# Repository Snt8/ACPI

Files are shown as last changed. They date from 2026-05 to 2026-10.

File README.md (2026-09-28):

# 🚦 ACPI: Asistente de Cruce Peatonal para Invidentes v3.0 👨‍🦯➡️

## Descripción General
**ACPI** es un sistema **IoT de asistencia a la movilidad** diseñado para brindar **autonomía y seguridad** a personas con discapacidad visual al cruzar calles en intersecciones semaforizadas.

El sistema combina **hardware en el borde (Edge Computing)** con sensores magnéticos e inerciales locales en un brazalete (wearable) y en un semáforo (infraestructura). Utiliza comunicación local ultrarrápida (ESP-NOW) entre nodos y telemetría por Bluetooth Low Energy (BLE) hacia una aplicación móvil integrada con **Grafana Cloud** para monitorear la seguridad de la sesión.

---

## Contenido
El repositorio principal se divide en los siguientes componentes fundamentales:
- `/firmware/brazalete/` -> Código fuente (PlatformIO/C++) para el wearable (ESP32-C3 Super Mini).
- `/firmware/semaforo/` -> Código fuente (PlatformIO/C++) para la baliza de infraestructura (ESP32 DevKit V1).
- `/ACPIGPS/` -> Aplicación móvil Android nativa en Kotlin (Jetpack Compose).
- `/docs/` -> Documentación adicional y guías de configuración de la nube.
- `Justfile` -> Orquestador de tareas para compilación y *linting* automatizado.

---

## Explicación
### Arquitectura y Flujo de Procesamiento

El flujo de información se ejecuta de la siguiente forma:

```text
[Semáforo ESP32]  ──ESP-NOW──►  [Brazalete ESP32-C3]  ──BLE──►  [App Android]  ──HTTPS──►  [Grafana Cloud]
 QMC6308                         QMC6308 + MPU6050              GPS + Pasos
 2 LEDs simulan                  Brújula + Decisión              Registro sesiones
 semáforo                        Feedback háptico                Telemetría
 (sin WiFi/Internet)             FSM de 2Hz
```

1. **Semáforo (Infraestructura)**: Un ESP32 DevKit V1 equipado con un magnetómetro lee su orientación magnética estática y simula un ciclo de semáforo verde/rojo. Transmite su orientación (heading) y estado por ESP-NOW a 2Hz (cada 500ms).
2. **Brazalete (Wearable)**: Actúa como el centro de cómputo en el borde. Lee su orientación tilt-compensada (acelerómetro + magnetómetro), y calcula la diferencia angular frente a la infraestructura. Si detecta que el usuario está correctamente enfrentado (`|Δθ - 180°| < 30°`), provee feedback háptico diferenciado mediante dos micromotores de vibración.
3. **App Android**: Recibe mediante BLE los paquetes de telemetría del brazalete, controla geocercas y envía métricas asíncronas.
4. **Grafana Cloud**: Ingesta los datos del usuario asíncronamente para generar mapas y analíticas en tiempo real.

---

## Dependencias
- **Hardware**: 
  - ESP32-C3 Super Mini, ESP32 DevKit V1.
  - MPU6050 (Acelerómetro/Giroscopio) y QMC6308 (Magnetómetro I2C).
  - Micro-motores de vibración 3V tipo moneda.
- **Software**: 
  - [PlatformIO](https://platformio.org/) para el desarrollo y flasheo C++ del firmware.
  - [Just](https://github.com/casey/just) como *command runner* (opcional pero recomendado).
  - Android Studio para compilar la App.

---

## Ejemplo de Uso

Para compilar e inyectar el código en los microcontroladores usando PlatformIO, primero asegúrate de tener instaladas las dependencias.

Con **Just** (Recomendado):
```bash
# Compilar todo el ecosistema firmware
just compile-all

# Flashear el semáforo y el brazalete (asegúrate de conectarlos vía USB)
just flash-semaforo
just flash-brazalete
```

Sin **Just** (Usando PlatformIO CLI directo):
```bash
pio run -d firmware/brazalete --target upload
pio run -d firmware/semaforo --target upload
```

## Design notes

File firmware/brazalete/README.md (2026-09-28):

# Firmware Brazalete (Wearable ACPI)

## Descripción General
Este es el código fuente principal del **Nodo Maestro (Brazalete)** del proyecto ACPI. Diseñado para correr sobre un microcontrolador **ESP32-C3 Super Mini**, actúa como un procesador _Edge Computing_ portátil y de ultrabajo consumo. Es responsable de recopilar lecturas inerciales y magnéticas, evaluar la orientación peatonal contra las señales del semáforo, emitir respuestas físicas (hápticas) al usuario y transmitir los resultados de telemetría al smartphone.

---

## Contenido
- `platformio.ini` -> Archivo de configuración de construcción de PlatformIO (Framework `espressif32@6.9.0`).
- `include/` -> Constantes globales y configuraciones macro (`config.h`, `constantes.h`).
- `src/main.cpp` -> Punto de entrada del programa.
- `lib/` -> Submódulos independientes (brújula, sensores, control, motores, comunicación, utilidades).

---

## Explicación
El firmware está construido bajo un enfoque altamente modular y orientado a eventos discretos, implementando una **Máquina de Estados Finita (FSM)**.

En su estado nominal de `SENSING_CROSSING`, el brazalete ejecuta un ciclo de muestreo estricto a **2 Hz (cada 500ms)** en el que realiza las siguientes operaciones en menos de un milisegundo de CPU, maximizando el tiempo inactivo:
1. Lee los componentes vectoriales $g_x, g_y, g_z$ del MPU6050.
2. Extrae las lecturas crudas del QMC5883L y les aplica compensación ambiental _Hard-Iron_ mediante un _Leaky Integrator_.
3. Compensa tridimensionalmente el compás magnético (_Tilt Compensation_) para obtener el Heading puro.
4. Aplica una barrera protectora de movimiento brusco (_Safety Check_): Ignora lecturas si el Heading giró $>40^{\circ}$ en medio segundo.
5. Evalúa matemáticamente la diferencia frente al rumbo transmitido por el Semáforo.
6. Enciende los micro-motores usando rutinas no-bloqueantes.

---

## Dependencias
- **NimBLE-Arduino**: Biblioteca optimizada para gestionar Bluetooth Low Energy ocupando mucho menos memoria RAM y Flash que la biblioteca oficial, ideal para el restringido ESP32-C3.
- **Wire (I2C)**: Framework nativo de Arduino para la comunicación con los sensores.
- **ESP-NOW**: Protocolo ultrarrápido sin conexión de Espressif.

---

## Ejemplo de Uso

Dado que el entorno depende de PlatformIO, la construcción del brazalete se maneja desde la raíz del proyecto.

```bash
# Navegar a la raíz del proyecto ACPI
cd ../../

# Ejecutar el Linter de calidad de código
pio check -d firmware/brazalete

# Compilar el código
pio run -d firmware/brazalete

# Compilar y cargar en la ESP32-C3 por puerto USB
pio run -d firmware/brazalete --target upload
```

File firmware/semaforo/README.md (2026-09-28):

# Firmware Semáforo (Infraestructura ACPI)

## Descripción General
Este es el código fuente principal del **Nodo Esclavo (Semáforo)** del proyecto ACPI. Está diseñado para ejecutarse en una placa de desarrollo **ESP32 DevKit V1** (o compatible) anclada de manera estática y fija en la intersección peatonal.

Su misión principal es leer el campo magnético direccional permanente hacia donde cruza la calle (su propia orientación), simular visualmente mediante LEDs el estado de permiso de vía (Verde/Rojo para vehículos), y disparar de forma constante la información (telemetría) a los brazaletes cercanos usando difusión de radio (Broadcast).

---

## Contenido
- `platformio.ini` -> Archivo de configuración de construcción de PlatformIO (Framework `espressif32@6.9.0`).
- `include/` -> Constantes globales (Ej: Tiempos de duración de la luz verde o roja) y configuración (`config.h`, `const.h`).
- `src/main.cpp` -> Punto de entrada y Máquina de Estados Finita (FSM) basada en tiempo del semáforo.
- `lib/` -> Submódulos de hardware y red (`brujula`, `comunicacion`, `protocolo`).

---

## Explicación
A diferencia del brazalete que es impulsado por eventos, el semáforo está impulsado por reloj (Temporizadores):

1. Mantiene un bucle continuo de `millis()` verificando si la duración preconfigurada del estado actual del semáforo (ej: 30 segundos) ha expirado. Si expira, alterna el relé/LED y cambia internamente su estado booleano de `permitidoCruce`.
2. A una tasa paralela e independiente, lee periódicamente (ej: 2 Hz) el magnetómetro I2C para obtener su propia dirección en grados frente al polo magnético terrestre.
3. Empaqueta el tiempo que le resta a la luz actual, los grados y la validación en una estructura C empaquetada.
4. Invoca la radio ESP-NOW, propagando la carga en modo BROADCAST (Mac: `FF:FF:FF:FF:FF:FF`). Todo brazalete en rango capturará esta ráfaga de forma pasiva.

---

## Dependencias
- Librería base **Arduino.h**.
- Bus I2C de Espressif (`<Wire.h>`).

---

## Ejemplo de Uso

Para compilar y cargar localmente:

```bash
# Cambiar al directorio raíz
cd ../../

# Ejecutar linters de calidad
pio check -d firmware/semaforo

# Compilar para la placa DevKit
pio run -d firmware/semaforo

# Flashear al hardware conectado por USB
pio run -d firmware/semaforo --target upload
```

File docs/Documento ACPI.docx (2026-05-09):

ASISTENTE DE CRUCE PEATONAL PARA INVIDENTES

Andrea Carolina Cárdenas Rojas

Dilan Santiago Osorio Bernate

Nicolás Ernesto Rodríguez Avella

Asesora

Johanna Carolina Sánchez Ramírez

Escuela Tecnológica Instituto Técnico Central.

Especialidad de sistemas

Grupo III

2025

Tabla de Contenido

# Identificación del problema

Moverse por la ciudad puede parecer algo sencillo para la mayoría de las personas, pero para quienes tienen discapacidad visual, puede convertirse en una experiencia bastante difícil y hasta peligrosa. Desde salir de casa, caminar por una acera, esquivar obstáculos o cruzar una calle, cada paso puede representar un riesgo si no se cuenta con las herramientas necesarias. Uno de los momentos más delicados es al cruzar una calle con semáforo, ya que estos dispositivos están hechos para personas que pueden ver, sin tener en cuenta a quienes no pueden hacerlo. Esto significa que, aunque el semáforo esté en rojo para los vehículos, la persona con discapacidad visual no siempre tiene forma de saberlo con claridad y seguridad.

Aunque hay bastones y perros guías que les brindan orientación en muchos aspectos del camino, muchas veces no hay herramientas tecnológicas accesibles que realmente les ayuden a cruzar con confianza. En la mayoría de los casos, estas personas deben adivinar si pueden cruzar o esperar a que alguien las ayude, lo que no solo pone en riesgo su seguridad, sino que también afecta su autonomía, su tranquilidad y su capacidad de movilizarse libremente.

Es urgente responder a esta necesidad con una solución tecnológica accesible y práctica, que les proporcione mayor seguridad en el cruce de calles. Mejorar su experiencia de movilidad urbana no solo impacta en su calidad de vida, sino que también representa un paso hacia una ciudad más inclusiva, que considere a todos sus habitantes en igualdad de condiciones.

Dado esto, nuestro objetivo general es diseñar un sistema portátil con señal vibratoria que indique cuándo es seguro cruzar una calle con semáforo para brindar mayor seguridad y autonomía a personas con discapacidad visual en espacios urbanos.

# Investigación y Análisis

El proyecto ACPI busca crear un sistema asistido que ayude a personas con discapacidad visual a cruzar calles de manera más segura. Para lograrlo, se usan tecnologías como microcontroladores, comunicación inalámbrica, vibración háptica y posicionamiento GPS. Conocer los fundamentos técnicos y teóricos de estas herramientas es clave para asegurar que el sistema funcione bien, sea útil y tenga un impacto positivo en la sociedad.

Componentes clave:

- ESP32: Es un microcontrolador económico y potente con Wi-Fi y Bluetooth, ideal para proyectos inalámbricos. Gracias a su bajo consumo, es apto para dispositivos portátiles (Espressif Systems, 2020).
- ESP-NOW: Protocolo creado por Espressif que permite la comunicación directa entre dispositivos sin internet, útil en sistemas que requieren respuesta rápida y autónoma.
- Motor vibrador: Dispositivo pequeño que genera vibración como señal de alerta. Se usa comúnmente en celulares y relojes.
- GPS: Sistema que usa satélites para obtener ubicación en tiempo real. En este proyecto se emplea a través del celular del usuario (NASA, 2018).
- TP4056: Módulo que permite recargar baterías de litio de forma segura, evitando sobrecargas.
- XL6009: Elevador de voltaje que convierte, por ejemplo, 3.7V en 5V para alimentar componentes electrónicos.
- Arduino y C++: Arduino es una plataforma de desarrollo que se programa en C++, permitiendo controlar sensores y actuadores fácilmente, ideal para prototipos.

En varios países se han propuesto soluciones similares. En España, la aplicación SeeLight notifica a personas ciegas cuando el semáforo está en verde (Fundación Montemadrid, 2015). También, en Granada, LabIN desarrolló semáforos accesibles con botones y sonidos. Sin embargo, muchos de estos sistemas dependen de la verificación y uso respecto al celular del usuario o de infraestructura urbana costosa. ACPI busca ser más sencillo, portátil y económico, funcionando incluso en zonas sin internet ni semáforos sonoros, como entornos escolares o rurales.

Este proyecto se basa en la tecnología asistida, definida por la OMS (2004) como cualquier herramienta que mejora la funcionalidad de personas con discapacidad. También se relaciona con el modelo social de la discapacidad, que señala que las limitaciones no están en la persona, sino en el entorno. Bajo esta mirada, ACPI busca eliminar barreras a través de tecnología accesible y funcional.

Comprender estos conceptos técnicos y teóricos permite diseñar una solución que responda a las necesidades reales del usuario. Saber cómo funciona el ESP32, el protocolo ESP-NOW, los motores vibradores y los módulos de energía ayuda a tomar buenas decisiones al construir el prototipo. Además, los antecedentes muestran que esta necesidad existe y que es posible hacerla realidad con herramientas simples, económicas y bien diseñadas.

## Propuesta de solución

Nombre del proyecto: ACPI – Asistente de Cruce para Personas Invidentes

Descripción de la solución: ACPI es un sistema portátil diseñado para mejorar la seguridad de personas con discapacidad visual al momento de cruzar calles con semáforo. El dispositivo consiste en una pulsera que recibe de manera inalámbrica, mediante tecnología ESP32 y protocolo ESP-NOW, la información procesada desde el entorno del semáforo. Al determinar que el cruce es seguro, la pulsera emite una señal vibratoria clara y perceptible para el usuario.

La solución combina el uso del microcontrolador ESP32 con componentes de bajo consumo energético, alimentados por una batería recargable y programados en C++ a través de la plataforma Arduino. Para futuras versiones, la aplicación móvil se integrará con el GPS y la brújula del celular, lo que permitirá funciones adicionales de ubicación y orientación sin necesidad de añadir más hardware al dispositivo.

Objetivos específicos:

1. Analizar las dificultades que enfrentan las personas con discapacidad visual al cruzar calles con semáforo para asegurar que el sistema responda a sus necesidades reales en contextos urbanos transitados.
2. Construir un módulo que detecte la luz roja del semáforo mediante un sensor de luz calibrado para enviar información clara al usuario desde un punto fijo cercano al semáforo.
3. Diseñar una pulsera portátil basada en ESP32 que reciba la señal del semáforo mediante comunicación inalámbrica y active un motor vibrador para alertar al usuario sobre el momento seguro de cruce.
4. Vincular la aplicación móvil con el GPS y la brújula del celular, de manera que el sistema quede preparado para futuras funciones de orientación y seguimiento de rutas en espacios urbanos.
5. Evaluar la comodidad, duración de la batería y facilidad de uso del sistema para asegurar que sea práctico en el día a día en manos de personas con discapacidad visual

Criterios de funcionamiento:

- El dispositivo debe recibir la señal del nodo semafórico en tiempo real.
- Debe vibrar únicamente cuando el cruce sea seguro.
- El sistema debe ser ligero, portátil y fácil de usar.
- La batería debe durar varios días y poder recargarse fácilmente.
- Debe operar sin fallos en la comunicación entre ambos dispositivos.
- Debe activarse y apagarse manualmente para ahorrar energía.

## Diseño del Prototipo

Lista de materiales:

- 2 módulos ESP32 (uno para el semáforo y otro para el usuario)
- 1 sensor de luz fotorresistencia LDR (para detectar el estado del semáforo)
- 1 motor vibrador (para la señal háptica)
- 1 módulo TP4056 (para carga segura de la batería)
- 1 batería de litio recargable de 3.7V
- 1 elevador de voltaje XL6009 (para alimentar los 5V de la pulsera)
- 1 interruptor deslizante con marca táctil física (muesca o relieve) para que el usuario pueda identificar por tacto las posiciones ON/OFF
- Cables Dupont
- Soldadura para circuito final
- Pulsera o carcasa impresa en 3D
- Computador con Arduino IDE y Android Studio instalado

Funcionamiento técnico:
Cuando el semáforo está en rojo para los vehículos (es decir, seguro para cruzar), el sensor de luz activa el ESP32 fijo, que envía una señal inalámbrica mediante ESP-NOW al dispositivo del usuario. Al recibir la señal, el ESP32 portátil activa el motor vibrador, indicando que es momento de cruzar. El sistema se apaga manualmente para conservar batería. La aplicación móvil complementará la experiencia usando el GPS y brújula del celular para ofrecer navegación y mejor orientación espacial.

Roles del equipo:

- Dilan: Programación del sistema en C++ (Arduino IDE), pruebas de comunicación ESP-NOW, diseño físico del prototipo, armado del circuito y cuidado del montaje portátil.
- Andrea: Diseño y programación de la aplicación móvil, integración del GPS y brújula del celular, desarrollo de README.md.
- Nicolás: Documentación escrita, organización general del cronograma y entregables, investigación técnica de componentes, redacción y soporte teórico.

## Construcción y Pruebas

Prototipo 1 (Micro: bit)

Proceso de construcción:

1. Diseño de la carcasa en software 3D con espacios para Micro: bit, motor vibrador y batería con su respectiva carcasa.
2. Impresión en PLA rígido de toda la estructura en dos piezas (ver foto).
3. Montaje de componentes dentro de la carcasa: Micro: bit y motor vibrador.
4. Conexionado de los cables de señal y alimentación con soldadura y cinta aislante.
5. Ajuste de la pulsera al brazo con correas elásticas.

Resultados:

- El Micro: bit y el motor vibrador funcionaron correctamente al enviar la señal.
- La carcasa protegió bien los componentes y la batería se mantuvo estable durante el uso.

Errores y limitaciones:

- La rigidez del PLA hacía la pulsera muy incómoda para la muñeca.
- Los cables quedaron muy expuestos y voluminosos, dificultando el uso diario.
- El diseño no era práctico ni estéticamente atractivo.

Fotos: (ver anexo)

Prototipo 2 (plástico flexible con ESP32)

Proceso de construcción:

Se plantea un rediseño completo de la carcasa, adaptándola al uso del microcontrolador ESP32 y a los demás componentes electrónicos. La estructura busca ser más compacta y modular, facilitando el montaje y el mantenimiento.

La carcasa sería en un plástico flexible para mejorar la comodidad al contacto con la piel y permitir un ajuste más ergonómico en la muñeca del usuario. El diseño se divide en dos módulos principales: uno destinado a alojar la electrónica (ESP32, batería y módulo de carga) y otro para la disposición de los cables, con el fin de optimizar el espacio y mejorar la organización interna. El montaje está previsto mediante encajes pequeños y una correa de silicona ajustable, lo que facilita tanto el uso cotidiano como el reemplazo de piezas en caso necesario.

Como referencia, se incluirá una fotografía del dispositivo sin carcasa, mostrando la disposición inicial de la pulsera con los componentes expuestos, lo que permite visualizar la organización interna antes del encapsulado final.

Fotos: (ver anexo)

# Evaluación del Prototipo

Resultados generales:
El prototipo ACPI logró cumplir su función principal de asistir al usuario en el cruce de calles, mediante la sincronización con semáforos y la transmisión de alertas vibratorias. En pruebas controladas, el sistema respondió adecuadamente y permitió validar la interacción entre la aplicación móvil y la pulsera.

Limitaciones encontradas:

- Autonomía de la batería limitada a menos de 8 horas.
- Incompatibilidad con algunos modelos de celulares Android/iOS.
- Carcasa poco ergonómica y de tamaño incómodo para muñecas pequeñas.
- Sensibilidad de la detección a cambios de luz ambiente (día/noche).
- Presupuesto reducido para mantenimiento o reemplazo de piezas.

Problemas técnicos:

- Pérdida de señal entre el celular/ESP32 y la pulsera en zonas con interferencia.
- Retraso en la sincronización con los semáforos cuando la vibración no es precisa.
- Riesgo de deterioro rápido en la correa y falta de resistencia al agua.

Análisis con Diagrama de Ishikawa: (ver diagrama en anexo)

# Conclusiones y Recomendaciones

Conclusiones técnicas:

- El prototipo ACPI es funcional y logra asistir al usuario en el cruce de calles mediante alertas vibratorias sincronizadas con los semáforos.
- La integración entre la aplicación móvil, el ESP32 y la pulsera demuestra la viabilidad del uso de tecnologías accesibles en contextos sociales.
- Se adquirió experiencia en la implementación de sistemas electrónicos, programación móvil y validación de usabilidad con usuarios reales.

Recomendaciones futuras:

- Optimizar la autonomía del sistema incorporando baterías de mayor capacidad.
- Mejorar la ergonomía de la pulsera, reduciendo su tamaño y empleando materiales más resistentes al agua y al desgaste.
- Probar el funcionamiento del sistema completo (sensor y pulsera) en un entorno para comprobar la efectividad de la comunicación y la señal vibratoria con usuarios simulando situaciones reales de cruce
- Realizar pruebas en entornos reales con usuarios finales para refinar la precisión de la sincronización y la usabilidad del dispositivo.

# Anexos

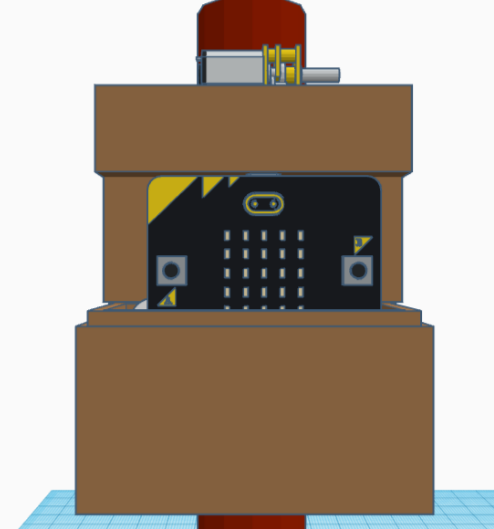
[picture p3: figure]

Prototipo 1 (Micro: bit)

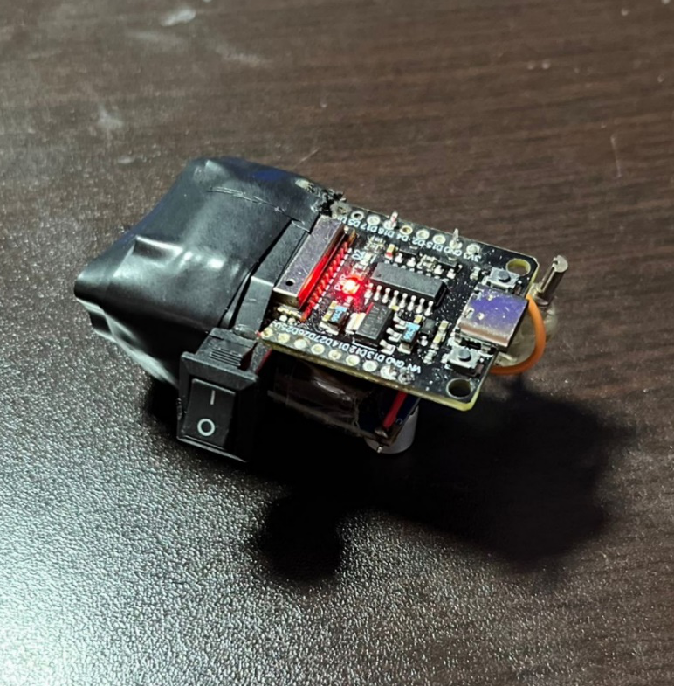
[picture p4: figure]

Prototipo 2 sin carcasa

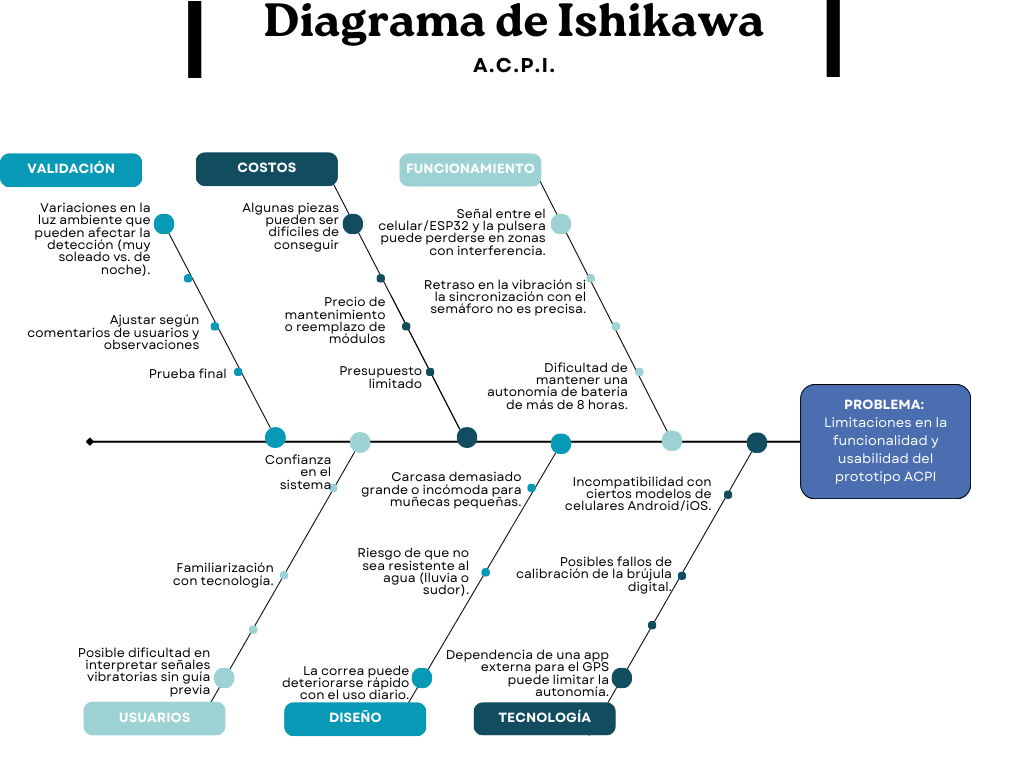
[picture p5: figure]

Análisis con Diagrama de Ishikawa

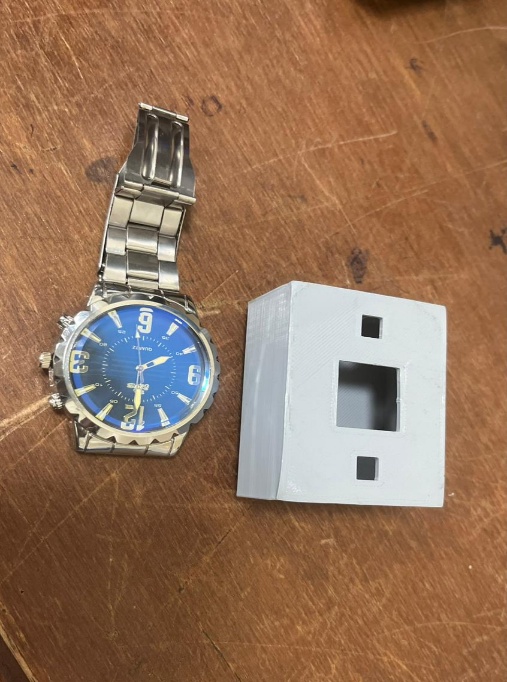
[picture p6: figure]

Imagen 1 Comparación de tamaños del reloj

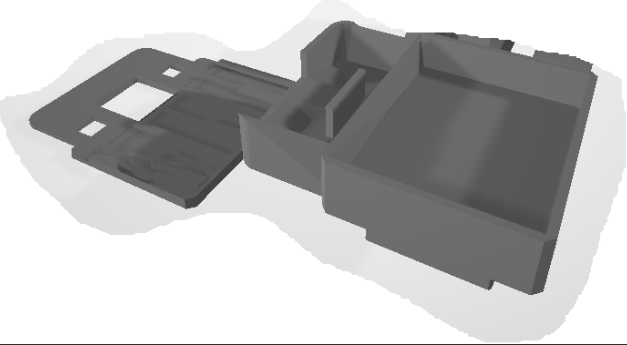
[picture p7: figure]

Imagen 2 Diseño previo de la pulsera

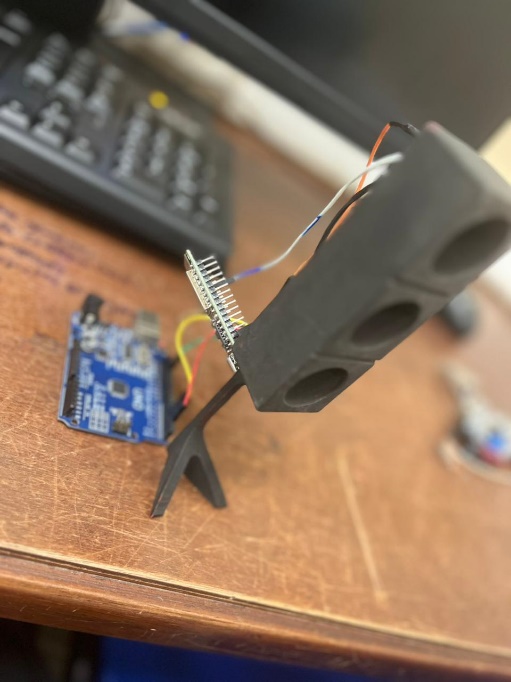
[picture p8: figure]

Imagen 3 Nuevo diseño con ESP-32

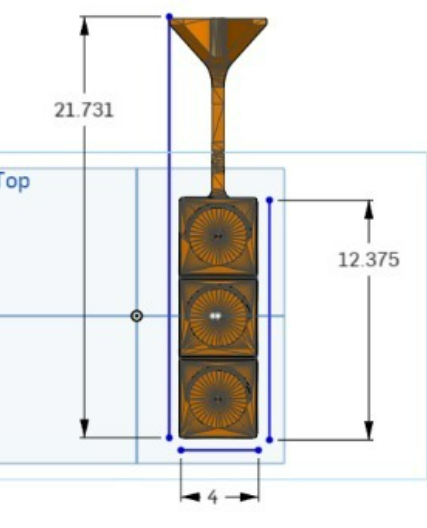
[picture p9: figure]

Imagen 4 Nuevo diseño con ESP-32

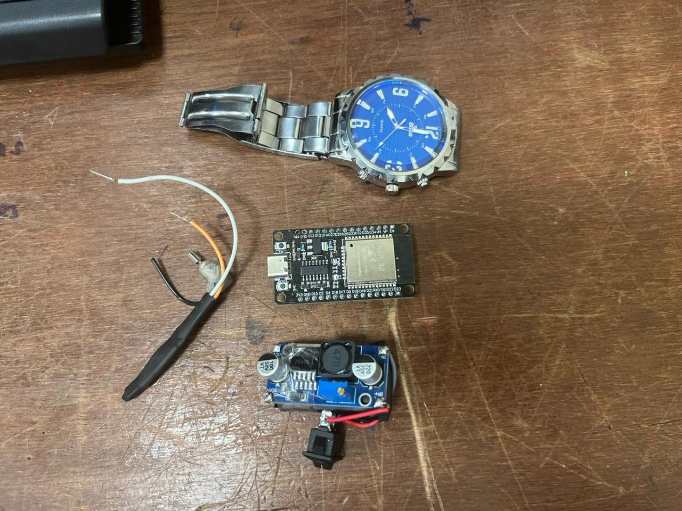
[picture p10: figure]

Imagen 5 Comparación tamaños

# Referencias

- CityTV. (2024, 14 de marzo). Bogotá tendría un déficit de semáforos sonoros para personas ciegas. El Tiempo. https://citytv.eltiempo.com/programas/citynoticias-del-mediodia/bogota-tendria-un-deficit-de-semaforos-sonoros-para-personas-ciegas_63112
- Congreso de Colombia. (2013). Ley 1618 de 2013: Por medio de la cual se establecen las disposiciones para garantizar el pleno ejercicio de los derechos de las personas con discapacidad. Diario Oficial No. 48.717. https://www.funcionpublica.gov.co/eva/gestornormativo/norma.php?i=52081
- LaBiN Granada. (s.f.). Semáforos para invidentes. Laboratorio de Innovación Pública de Granada. https://labingranada.org/idea/semaforos-para-invidentes/

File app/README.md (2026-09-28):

# ACPI Android Mobile Application (ACPIGPS)

## Descripcion General
La aplicación móvil **ACPIGPS** actúa como el puente de comunicaciones central del ecosistema ACPI. Su función principal es conectarse mediante **Bluetooth Low Energy (BLE)** al Brazalete Inteligente (ESP32-C3), procesar sus notificaciones de estado y orientación magnética en tiempo real, guiar al peatón de manera visual/auditiva y reportar las métricas agregadas de cada sesión de cruce de forma segura y resiliente hacia el backend de **Grafana Cloud** mediante payloads JSON simplificados.

## Contenido
La aplicación está organizada en torno a los siguientes archivos y submódulos principales en `app/src/main/java/com/example/acpigps/`:
- **[MainActivity.kt](file:///c:/Users/sntav/programacion/ACPI/ACPIGPS/app/src/main/java/com/example/acpigps/MainActivity.kt)**: Punto de entrada de la UI y gestión de navegación basada en Jetpack Compose.
- **[BLEManager.kt](file:///c:/Users/sntav/programacion/ACPI/ACPIGPS/app/src/main/java/com/example/acpigps/BLEManager.kt)**: Manejador GATT cliente que gestiona el escaneo, emparejamiento, suscripción a notificaciones y envío de comandos al brazalete.
- **[GrafanaReporter.kt](file:///c:/Users/sntav/programacion/ACPI/ACPIGPS/app/src/main/java/com/example/acpigps/GrafanaReporter.kt)**: Módulo encargado del formateo de telemetría y su envío mediante HTTP POST asíncrono con un buffer resiliente ante pérdidas de conectividad.
- **[MonitoringService.kt](file:///c:/Users/sntav/programacion/ACPI/ACPIGPS/app/src/main/java/com/example/acpigps/MonitoringService.kt)**: Servicio en primer plano (Foreground Service) que garantiza que las conexiones BLE y de red sigan activas incluso si la pantalla se apaga.
- **[WalkDirectionDetector.kt](file:///c:/Users/sntav/programacion/ACPI/ACPIGPS/app/src/main/java/com/example/acpigps/WalkDirectionDetector.kt)**: Detector lógico de pasos y patrones de desplazamiento.
- **[SessionLogger.kt](file:///c:/Users/sntav/programacion/ACPI/ACPIGPS/app/src/main/java/com/example/acpigps/SessionLogger.kt)**: Registro local en formato de texto dentro del almacenamiento del dispositivo.
- **[BrazaleteData.kt](file:///c:/Users/sntav/programacion/ACPI/ACPIGPS/app/src/main/java/com/example/acpigps/BrazaleteData.kt)**: Modelo de datos que mapea la telemetría recibida por BLE.

## Explicacion
### 1. Comunicación BLE (GATT Cliente)
La app implementa el perfil GATT cliente interactuando con los UUIDs definidos en el firmware del brazalete:
- **Servicio Principal**: `12345678-1234-1234-1234-123456789abc`
- **Característica TX (Notificación)**: `87654321-4321-4321-4321-cba987654321` (Recibe el JSON con rumbo, alineación y estado de cruce cada 500 ms).
- **Característica RX (Escritura)**: `11111111-2222-3333-4444-555555555555` (Envía comandos de control o cuadrantes de rumbo al ESP32).

### 2. Resiliencia de Telemetría (GrafanaReporter)
Para cumplir con los estándares de bajo consumo y resiliencia, `GrafanaReporter` implementa un buffer circular en memoria (`ConcurrentLinkedQueue`) de hasta 100 elementos. 
- Al completarse una sesión, el JSON se añade a la cola y se intenta realizar el POST asíncrono usando `OkHttpClient`.
- Si la conexión de red falla, el payload se mantiene en cola y se reintenta en el próximo envío.
- Si las credenciales (`grafana_url` y `grafana_token`) no se encuentran configuradas en `SharedPreferences` (bajo el archivo `app_prefs`), el reporte falla silenciosamente para no bloquear la ejecución principal.

## Dependencias
Las principales dependencias declaradas en el archivo de construcción Gradle de la app son:
- **OkHttp (v4.x+)**: Para las peticiones de red asíncronas y seguras hacia Grafana Cloud.
- **Android Bluetooth Suite**: APIs nativas de Android SDK para operaciones de escaneo y conectividad GATT.
- **Jetpack Compose**: Framework UI moderno para la renderización de pantallas.
- **Lifecycle & LiveData**: Gestión del estado reactivo entre la lógica de negocio y la interfaz de usuario.

## Ejemplo de Uso
A continuación se ilustra cómo el servicio interactúa con el reportero de telemetría al finalizar un cruce peatonal:

```kotlin
// Instanciación del reportero
val reporter = GrafanaReporter(context)

// Creación de las métricas de la sesión
val metrics = JSONObject().apply {
    put("duration_sec", 30)
    put("waiting_sec", 12)
    put("steps", 45)
    put("panics", 0)
    put("lat", 19.4326)
    put("lon", -99.1332)
}

// Envío asíncrono y resiliente
reporter.sendSessionTelemetry(
    deviceId = "ACPI_Brazalete",
    sessionId = UUID.randomUUID().toString(),
    status = 1, // 1 = Cruce exitoso y alineado
    metrics = metrics
)
```

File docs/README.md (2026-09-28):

# Especificaciones de Protocolos, Telemetría e Integración (ACPI)

## Descripcion General
Este directorio contiene la documentación técnica y las especificaciones de arquitectura para la comunicación de red, los protocolos inalámbricos y la integración con el sistema de telemetría y visualización de datos en la nube. Define cómo interactúan el Brazalete Inteligente, el Semáforo, la Aplicación Móvil y el panel de control de Grafana Cloud.

## Contenido
El directorio incluye los siguientes documentos técnicos especializados:
- **[ble-protocol.md](file:///c:/Users/sntav/programacion/ACPI/docs/ble-protocol.md)**: Especificación técnica detallada del protocolo de comunicación Bluetooth Low Energy (BLE) entre el Brazalete (servidor GATT) y el dispositivo Android (cliente GATT).
- **[grafana-setup.md](file:///c:/Users/sntav/programacion/ACPI/docs/grafana-setup.md)**: Guía paso a paso para la configuración del ingestor de datos en Grafana Cloud, mapeo de variables JSON de telemetría y diseño de paneles recomendados.

## Explicacion
### 1. Topología Inalámbrica Dual
El sistema ACPI utiliza una separación estricta de protocolos según el dispositivo:
- **Brazalete (ESP32-C3)**: Utiliza **BLE únicamente** para comunicarse con el celular del peatón. Tiene prohibido levantar la pila Wi-Fi para optimizar la batería.
- **Semáforo (ESP32 DevKit V1)**: Transmite periódicamente su orientación y estado magnético al brazalete a través de **ESP-NOW** en modo broadcast (2Hz).
- **Celular (App Android)**: Recibe los datos vía BLE y, cuando finaliza una sesión de cruce, utiliza la red móvil (Wi-Fi o Datos) para enviar las métricas agregadas por HTTP Push (POST) a Grafana Cloud.

### 2. Formato del Payload de Telemetría
Para reducir la carga en la red móvil del usuario, el JSON de sesión se mantiene en una sola jerarquía (plano), facilitando la ingesta directa en bases de datos de series temporales (como InfluxDB o Prometheus):
- **`device_id`**: Identificador de hardware.
- **`session_id`**: UUID generado por la aplicación para rastrear el cruce actual.
- **`status`**: Estado final codificado numéricamente (`0` = Espera, `1` = Cruce seguro/alineado, `2` = Desalineado, `3` = Alerta de pánico).
- **Métricas físicas**: Pasos (`steps`), duración (`duration_sec`), y geolocalización (`lat` y `lon`).

## Dependencias
Para implementar e interactuar con estos protocolos e integraciones, se requiere:
- **Pila BLE v4.2 o superior**: Compatible con GATT en ESP32-C3 y el sistema operativo Android.
- **Servicio Grafana Cloud (Free Tier)**: O bien un gateway/broker local (Mosquitto/MQTT) capaz de procesar peticiones HTTP JSON.

## Ejemplo de Uso
Ejemplo de cómo reportar manualmente un evento de cruce de prueba al endpoint HTTP de Grafana Cloud (o gateway compatible) utilizando `curl`:

```bash
curl -X POST "https://influx-prod-13-prod-us-east-0.grafana.net/api/v1/push" \
  -H "Authorization: Bearer glc_eyJ..." \
  -H "Content-Type: application/json" \
  -d '{
    "device_id": "ACPI_Brazalete_Test",
    "session_id": "99999999-9999-9999-9999-999999999999",
    "status": 1,
    "timestamp": 1780704000000,
    "duration_sec": 28,
    "waiting_sec": 8,
    "steps": 32,
    "panics": 0,
    "lat": 19.4326,
    "lon": -99.1332
  }'
```

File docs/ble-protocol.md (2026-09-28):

# Protocolo de Comunicación BLE (Brazalete ◄► App)

Este documento detalla el protocolo de comunicación inalámbrica vía **Bluetooth Low Energy (BLE)** utilizado entre el **Brazalete Inteligente** (Servidor GATT) y la **Aplicación Android** (Cliente GATT).

---

## 1. Identificación y Servicios GATT

El brazalete se anuncia con el nombre del dispositivo **`ACPI_Brazalete`**.

### UUIDs del Perfil GATT:
- **Servicio Principal**: `12345678-1234-1234-1234-123456789abc`
- **Característica de Transmisión (TX - Notificaciones)**: `87654321-4321-4321-4321-cba987654321`
  * *Permiso*: Notificación (Notify). El brazalete empuja datos aquí periódicamente.
- **Característica de Recepción (RX - Escritura)**: `11111111-2222-3333-4444-555555555555`
  * *Permiso*: Escritura sin respuesta (Write Without Response / Write). La app escribe comandos aquí.

---

## 2. Payload de Telemetría (Brazalete ──► App)

El brazalete transmite cada **500 ms** (cuando hay conexión y está en estado activo de cruce o pánico) un JSON compacto en texto plano UTF-8 a través de la característica **TX**:

```json
{"hd":135,"st":1,"ok":true,"tr":18,"bt":-1}
```

### Especificación de Campos:

| Clave | Tipo | Rango | Descripción |
|---|---|---|---|
| **`hd`** | Entero | `0` a `359` | **Heading**: Orientación magnética tilt-compensada actual del brazalete. |
| **`st`** | Entero | `0` a `3` | **Status**: Estado actual del cruce determinado por el brazalete:<br>• `0`: Espera (Semáforo en verde de autos, peatón debe esperar).<br>• `1`: Cruce Permitido (Semáforo en rojo de autos, peatón alineado).<br>• `2`: Orientación Incorrecta (El peatón no está mirando en la dirección del semáforo).<br>• `3`: Alerta de Pánico (Botón de pánico presionado por el usuario). |
| **`ok`** | Booleano | `true` / `false` | **Alineación**: `true` si el heading del brazalete coincide con el heading del semáforo dentro del umbral (±45°). |
| **`tr`** | Entero | `0` a `255` | **Tiempo Restante**: Segundos restantes en el estado actual del semáforo. |
| **`bt`** | Entero | `-1` o `0` a `100` | **Batería**: Nivel de batería en porcentaje. Si el hardware no posee divisor resistivo en ADC para medir batería, se reportará **`-1`** (no disponible). |

---

## 3. Comandos de Control (App ──► Brazalete)

La aplicación móvil puede enviar comandos a través de la característica **RX** para propósitos de prueba y depuración:

- **`TEST_ALERT`**: Genera un pulso haptico de prueba de corta duración en ambos motores del brazalete para comprobar la conectividad del vibrador.
- **`VIBRATE_STOP`**: Detiene cualquier vibración activa inmediatamente.

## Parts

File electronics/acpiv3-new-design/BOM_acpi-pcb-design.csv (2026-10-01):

ID | Name | Designator | Footprint | Quantity | Manufacturer Part | Manufacturer | Supplier | Supplier Part | Price
1 | 100nF | C1,C2 | CAP-TH_L5.0-W2.5-P5.08-D0.7 | 2 | CC2A104ZC1ID3F7C30MF | Dersonic(德尔创) | LCSC | C254109 | 0.034
2 | 100uF | C3,C4 | CAP-TH_BD6.3-P2.50-D0.6-FD | 2 | OLKC1102A220MF | Ymin(永铭) | LCSC | C19193647 | 0.076
3 | CABLE-2P | CN1,CN2,CN3 | CABLE-2P-P3.81 | 3
4 | 1N5819散装0658 | D1,D2,D3 | DO-41_BD2.4-L4.7-P8.70-D0.9-RD | 3 | 1N5819散装0658 | YFW(佑风微) | LCSC | C2906380 | 0.03
5 | 2N2222 | Q1,Q2 | TO-92-P2.54-CASERA | 2 | 2N2222A | ST(先科) | LCSC | C118536 | 0.04
6 | 1k | R1,R2 | R_AXIAL-0.3 | 2
7 | 12 | R3 | R_AXIAL-0.5 | 1
8 | ESP32C3-SUPERMINI | U1 | ESP32C3-SUPERMINI-THT | 1 | ESP32C3-SuperMini | null | LCSC | C9900147397
9 | MPU9250 | U2 | MPU9250 | 1
10 | HMC5883L GY271 module | U3 | HMC5883L GY271 MODULE | 1
11 | TP4056充电源模块板(TYPE-C) | U4 | PWRM-TH_TP4056 | 1 | TP4056充电源模块板(Type-C) | null | LCSC | C9900049108
12 | ON OFF | U6 | SW-TH_SS12D00G4 | 1 | SS12D00G4 | YIZHI(逸致) | LCSC | C50377148 | 0.017

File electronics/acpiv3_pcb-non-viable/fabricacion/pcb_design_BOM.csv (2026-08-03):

Designator | Value | Footprint | LCSC Part# | Qty
C1,C2 | 10uF | Capacitor_SMD:C_0805_2012Metric |  | 2
C3,C4,C8,C9 | 0.1uF | Capacitor_SMD:C_0603_1608Metric |  | 4
C5 | 2.2nF | Capacitor_SMD:C_0603_1608Metric |  | 1
C6 | 2.2uF | Capacitor_SMD:C_0805_2012Metric |  | 1
C7 | 1uF | Capacitor_SMD:C_0603_1608Metric |  | 1
C10,C11 | 1uF | Capacitor_SMD:C_0805_2012Metric |  | 2
D1,D2 | 1N4148W | Diode_SMD:D_SOD-123 | C81598 | 2
J1 | USB_C_Receptacle_USB2.0_16P | Connector_USB:USB_C_Receptacle_HRO_TYPE-C-31-M-12 | C165948 | 1
J2,J3,J4 | JST_PH_S2B-PH-K | Connector_JST:JST_PH_S2B-PH-K_1x02_P2.00mm_Horizontal | C265016 | 3
Q1,Q2 | MMBT3904 | Package_TO_SOT_SMD:SOT-23 | C20526 | 2
R1,R2 | 5.1k | Resistor_SMD:R_0603_1608Metric |  | 2
R3,R4 | 1k | Resistor_SMD:R_0603_1608Metric |  | 2
R5,R6,R7,R8,R9 | 4.7k | Resistor_SMD:R_0603_1608Metric |  | 5
R10 | 1M | Resistor_SMD:R_0603_1608Metric |  | 1
SW1 | SW_SPDT | Button_Switch_SMD:SW_SPDT_Shouhan_MSK12C02 | C431540 | 1
U1 | AP2112K-3.3 | Package_TO_SOT_SMD:SOT-23-5 | C51118 | 1
U2 | ESP32-C3-WROOM-02 | RF_Module:ESP32-C3-WROOM-02 | C2934560 | 1
U3 | MPU-6050 | Sensor_Motion:InvenSense_QFN-24_4x4mm_P0.5mm | C24112 | 1
U4 | QMC6308 | ACPI_QMC6308:WLCSP-4_L0.8-W0.8-R2-C2-P0.40-BL | C462705 | 1
U5 | AP2112K-1.8 | Package_TO_SOT_SMD:SOT-23-5 | C176944 | 1
U6 | TXS0102DCU | Package_SO:VSSOP-8_2.3x2mm_P0.5mm | C53434 | 1
U7 | MCP73831-2-OT | Package_TO_SOT_SMD:SOT-23-5 | C424093 | 1

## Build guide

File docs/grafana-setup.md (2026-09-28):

# Configuración de Telemetría con Grafana Cloud

Este documento describe cómo configurar una cuenta gratuita en **Grafana Cloud** y conectarla con la aplicación Android de **ACPI v2.0** para visualizar la telemetría del sistema en tiempo real.

---

## 1. Crear una Cuenta y Obtener Credenciales

1. Regístrate en una cuenta gratuita de **Grafana Cloud** en [grafana.com](https://grafana.com/).
2. En tu consola de Grafana, navega a **Access Policies** y genera un nuevo Token de API con permisos de escritura.
3. Toma nota del endpoint HTTP proporcionado. Si utilizas el plugin de InfluxDB o un recolector JSON compatible, el endpoint típicamente tiene un formato como:
   `https://<grafana-instance-host>/api/v1/push` o `https://<influx-host>/api/v2/write`

---

## 2. Configuración en la App Android

El `GrafanaReporter` de la aplicación Android carga de manera dinámica la URL del servidor y el Token desde las SharedPreferences. Puedes configurarlos programáticamente o a través de la UI de la aplicación (preferencias) guardando las siguientes claves en el archivo `app_prefs`:

- **Key:** `grafana_url`  
  **Value:** La URL de push de Grafana Cloud (ejemplo: `https://influx-prod-13-prod-us-east-0.grafana.net/api/v1/push`)
- **Key:** `grafana_token`  
  **Value:** Tu Token de API de Grafana (ejemplo: `glc_eyJ...`)

*Si estas claves no están configuradas en SharedPreferences, los datos de telemetría fallarán silenciosamente para no interrumpir el flujo de seguridad principal del usuario.*

---

## 3. Contrato de Datos (Payload JSON)

Cada sesión de cruce finalizada envía un payload JSON aplanado con el siguiente formato:

```json
{
  "device_id": "ACPI_Brazalete",
  "session_id": "8fa538e1-5e93-4a11-8254-cd6ef2802d28",
  "status": 1,
  "timestamp": 1780704000000,
  "duration_sec": 35,
  "waiting_sec": 15,
  "steps": 24,
  "panics": 0,
  "allowed_cruce": 1,
  "lat": 19.4326,
  "lon": -99.1332
}
```

### Campos Enviados:
- **`device_id`**: Identificador único del brazalete.
- **`session_id`**: Identificador único (UUID) de la sesión de cruce del peatón.
- **`status`**: Estado final de la sesión:
  - `0` = Espera / Seguro
  - `1` = Cruce exitoso y permitido
  - `2` = Orientación incorrecta
  - `3` = Pánico/Alerta crítica
- **`duration_sec`**: Duración total del cruce en segundos.
- **`waiting_sec`**: Tiempo total que esperó el peatón antes de poder cruzar (st = 0).
- **`steps`**: Número de pasos detectados durante el cruce.
- **`panics`**: Número de veces que el usuario presionó el botón de pánico.
- **`lat` / `lon`**: Coordenadas GPS de finalización del cruce.

---

## 4. Paneles Recomendados para el Dashboard

Una vez que los datos fluyen a tu base de datos de series temporales en Grafana, se recomienda configurar los siguientes paneles:

### A. Mapa de Calor / Geolocalización (Geomap)
- **Visualización:** Geomap
- **Campos:** `lat` y `lon`
- **Utilidad:** Muestra en un mapa interactivo todos los cruces del usuario, marcando con colores (verde, amarillo, rojo) los cruces exitosos, fallidos o de pánico.

### B. Línea de Tiempo de Estados (State Timeline)
- **Visualización:** State Timeline
- **Campos:** `status`
- **Mapeo de Colores:**
  - `0` (Espera) -> Gris
  - `1` (Cruce Exitoso) -> Verde
  - `2` (Desalineado) -> Naranja
  - `3` (Pánico) -> Rojo Brillante

### C. Estadísticas de Movilidad (Stat / Gauge)
- **Visualización:** Stat o Gauge
- **Campos:** `steps` (Pasos totales caminados), `waiting_sec` (Tiempo de espera promedio en semáforos)
- **Utilidad:** Indicadores de rendimiento del usuario y eficiencia de los semáforos.

### D. Historial de Pánico (Table)
- **Visualización:** Table
- **Filtro:** `panics > 0` o `status == 3`
- **Utilidad:** Un registro claro para que familiares o cuidadores identifiquen las intersecciones más riesgosas donde el usuario requirió activar la alerta de pánico.

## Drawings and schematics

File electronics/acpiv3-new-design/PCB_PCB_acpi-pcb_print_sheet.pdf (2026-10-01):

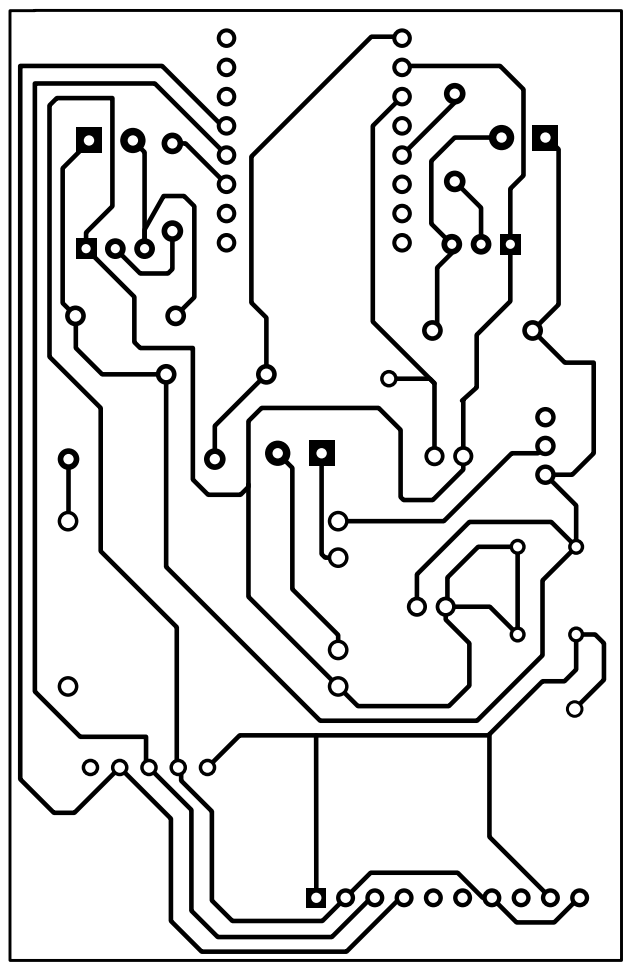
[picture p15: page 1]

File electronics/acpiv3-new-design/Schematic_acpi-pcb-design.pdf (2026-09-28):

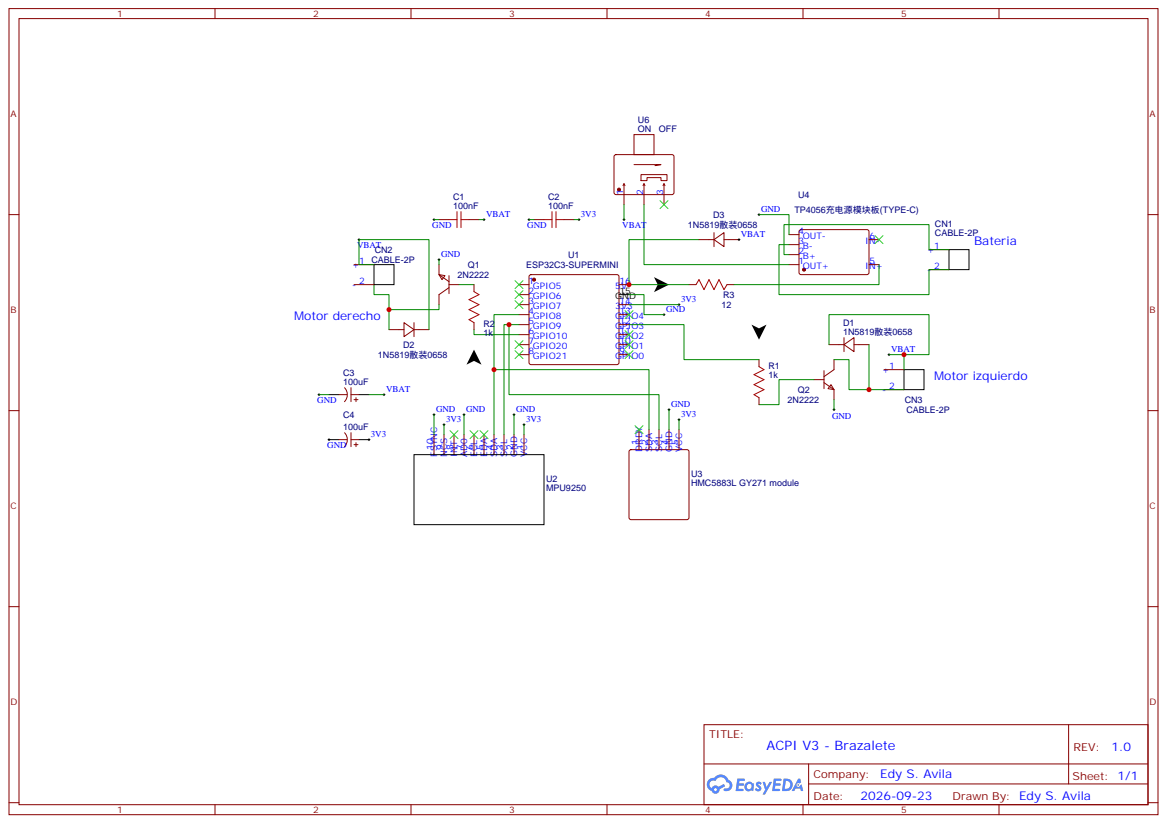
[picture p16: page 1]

Drawn By: Edy S. Avila

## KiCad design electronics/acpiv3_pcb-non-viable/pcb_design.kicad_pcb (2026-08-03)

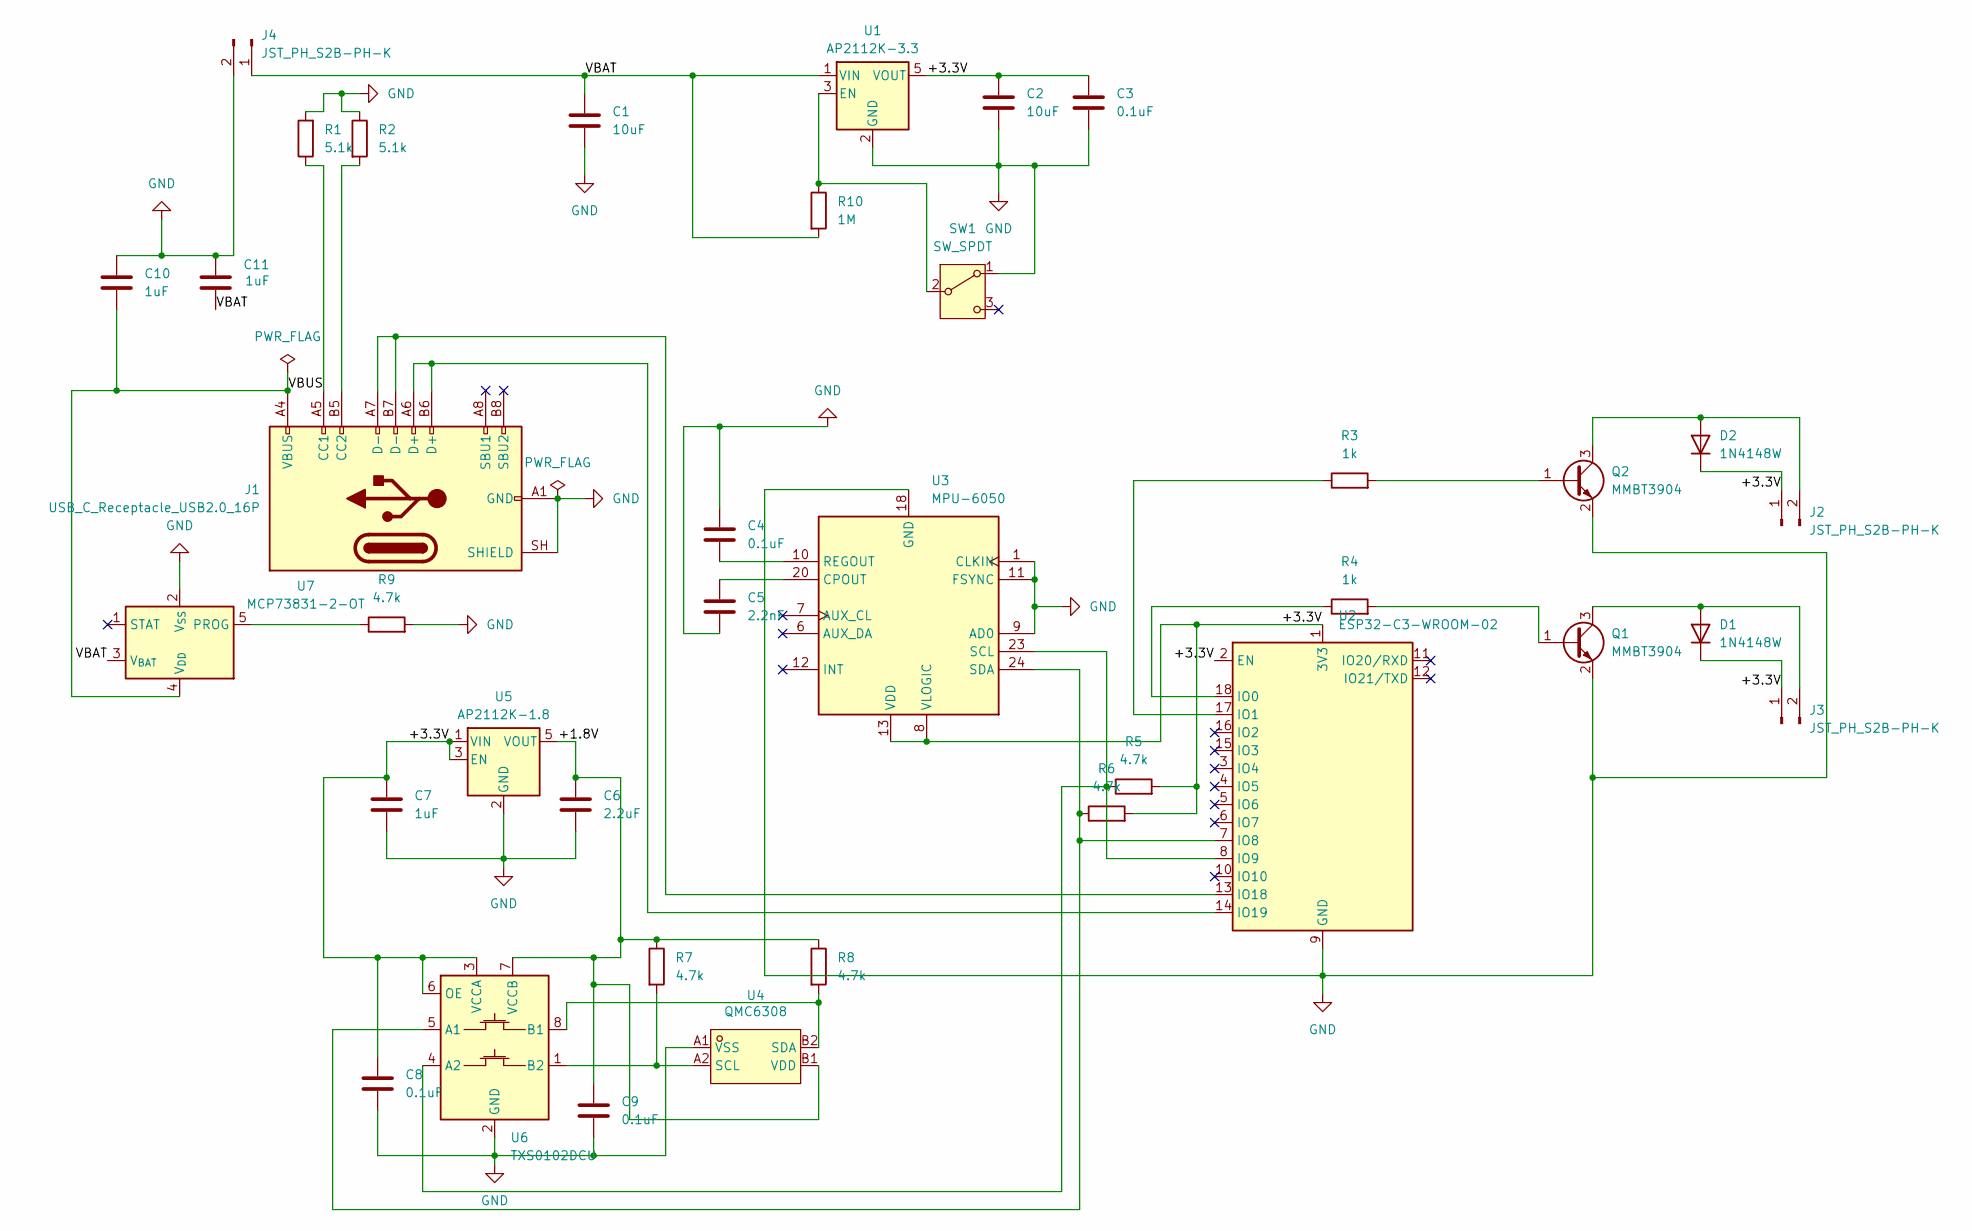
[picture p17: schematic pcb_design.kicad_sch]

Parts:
C1, C2: 10uF; C_0805_2012Metric
C3, C4, C8, C9: 0.1uF; C_0603_1608Metric
C5: 2.2nF; C_0603_1608Metric
C6: 2.2uF; C_0805_2012Metric
C7: 1uF; C_0603_1608Metric
C10, C11: 1uF; C_0805_2012Metric
D1, D2: 1N4148W; D_SOD-123; LCSC Part C81598
J1: USB_C_Receptacle_USB2.0_16P; USB_C_Receptacle_HRO_TYPE-C-31-M-12; LCSC Part C165948
J2, J3, J4: JST_PH_S2B-PH-K; JST_PH_S2B-PH-K_1x02_P2.00mm_Horizontal; LCSC Part C265016
Q1, Q2: MMBT3904; SOT-23; LCSC Part C20526
R1, R2: 5.1k; R_0603_1608Metric
R3, R4: 1k; R_0603_1608Metric
R5, R6, R7, R8, R9: 4.7k; R_0603_1608Metric
R10: 1M; R_0603_1608Metric
SW1: SW_SPDT; SW_SPDT_Shouhan_MSK12C02; LCSC Part C431540
U1: AP2112K-3.3; SOT-23-5; LCSC Part C51118
U2: ESP32-C3-WROOM-02; LCSC Part C2934560
U3: MPU-6050; InvenSense_QFN-24_4x4mm_P0.5mm; LCSC Part C24112
U4: QMC6308; WLCSP-4_L0.8-W0.8-R2-C2-P0.40-BL; MPN QMC6308; LCSC Part C462705
U5: AP2112K-1.8; SOT-23-5; LCSC Part C176944
U6: TXS0102DCU; VSSOP-8_2.3x2mm_P0.5mm; LCSC Part C53434
U7: MCP73831-2-OT; SOT-23-5; LCSC Part C424093

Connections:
/+1.8V: C6.1, C9.1, R7.1, R8.1, U4.B1 (VDD), U5.5 (VOUT), U6.7 (VCCB)
/+3.3V: C2.1, C3.1, C7.1, C8.1, D1.1 (K), D2.1 (K), J2.1, J3.1, R5.2, R6.2, U1.5 (VOUT), U2.1 (3V3), U2.2 (EN), U3.8 (VLOGIC), U3.13 (VDD), U5.1 (VIN), U5.3 (EN), U6.3 (VCCA), U6.6 (OE)
/VBAT: C1.1, C11.2, J4.1, R10.2, U1.1 (VIN), U7.3 (V_{BAT})
/VBUS: C10.2, J1.A4 (VBUS), J1.A9 (VBUS), J1.B4 (VBUS), J1.B9 (VBUS), U7.4 (V_{DD})
GND: C1.2, C2.2, C3.2, C4.2, C5.1, C6.2, C7.2, C8.2, C9.2, C10.1, C11.1, J1.A1 (GND), J1.A12 (GND), J1.B1 (GND), J1.B12 (GND), J1.SH (SHIELD), J4.2, Q1.2 (E), Q2.2 (E), R1.2, R2.1, R9.2, SW1.1 (A), U1.2 (GND), U2.9 (GND), U2.19 (GND), U3.1 (CLKIN), U3.9 (AD0), U3.11 (FSYNC), U3.18 (GND), U4.A1 (VSS), U5.2 (GND), U6.2 (GND), U7.2 (V_{SS})
unnamed: D1.2 (A), J3.2, Q1.3 (C)
unnamed: D2.2 (A), J2.2, Q2.3 (C)
unnamed: J1.A5 (CC1), R1.1
unnamed: J1.B5 (CC2), R2.2
unnamed: Q1.1 (B), R4.2
unnamed: Q2.1 (B), R3.2
unnamed: R10.1, SW1.2 (B), U1.3 (EN)
unnamed: R4.1, U2.18 (IO0)
unnamed: R3.1, U2.17 (IO1)
unnamed: R6.1, U2.7 (IO8), U3.24 (SDA), U6.5 (A1)
unnamed: R5.1, U2.8 (IO9), U3.23 (SCL), U6.4 (A2)
unnamed: J1.A7 (D-), J1.B7 (D-), U2.13 (IO18)
unnamed: J1.A6 (D+), J1.B6 (D+), U2.14 (IO19)
unnamed: C5.2, U3.20 (CPOUT)
unnamed: C4.1, U3.10 (REGOUT)
unnamed: R7.2, U4.A2 (SCL), U6.1 (B2)
unnamed: R8.2, U4.B2 (SDA), U6.8 (B1)
unnamed: R9.1, U7.5 (PROG)

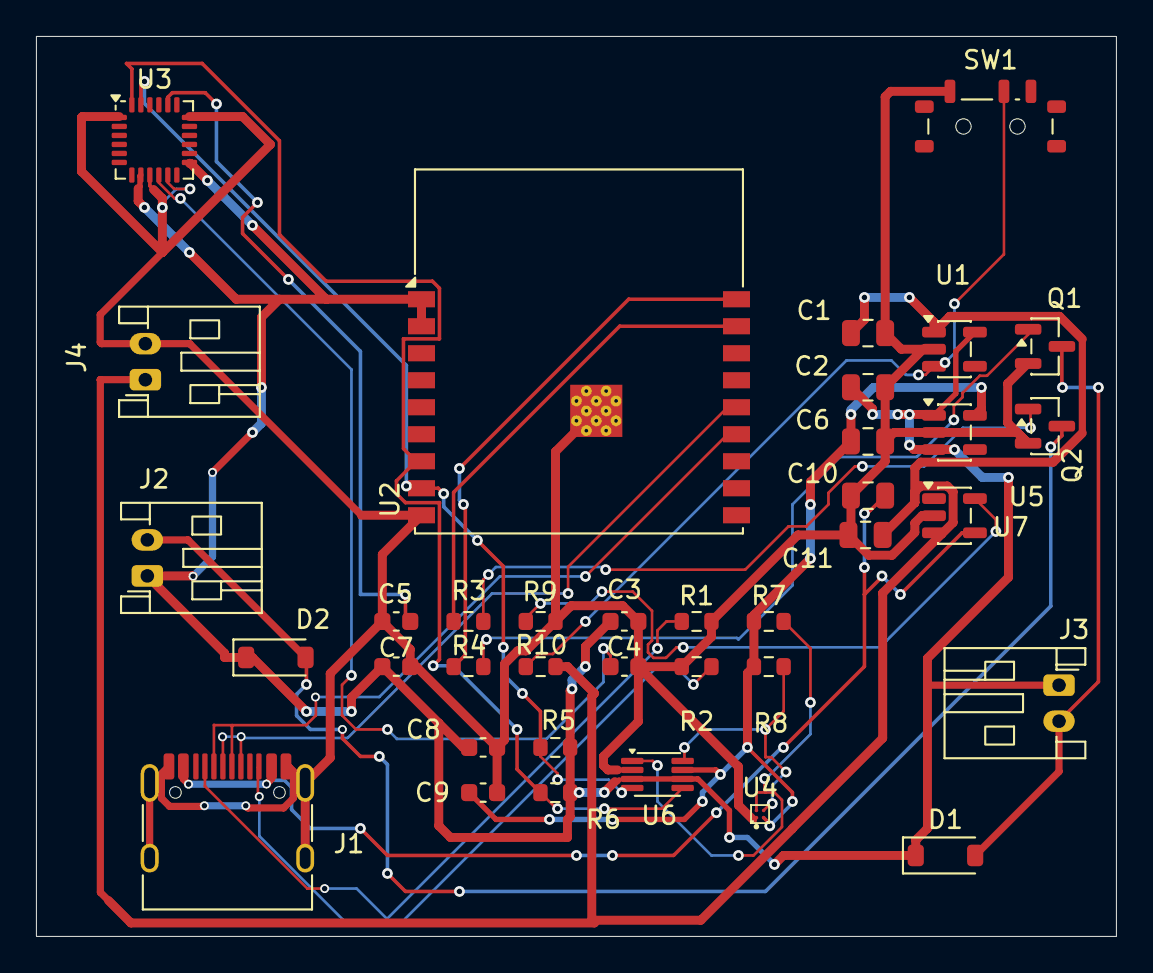
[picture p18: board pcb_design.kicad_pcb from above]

Board: 2 copper layers, 60.0 x 50.0 mm, 37 parts (0 on the bottom side), 23 nets.

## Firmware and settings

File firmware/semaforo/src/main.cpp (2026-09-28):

#include <Arduino.h>
#include <Wire.h>
#include "config.h"
#include "const.h"
#include "controlador_brujula.h"
#include "comunicador_brazalete.h"

// Estados del semáforo (punto de vista de los autos)
enum class EstadoSemaforoAutos {
    ROJO,  // Autos se detienen -> Peatón puede cruzar (permitidoCruce = 1)
    VERDE  // Autos avanzan    -> Peatón espera (permitidoCruce = 0)
};

// Variables de estado
EstadoSemaforoAutos estadoActualAutos = EstadoSemaforoAutos::VERDE;
unsigned long tiempoInicioEstado = 0;
unsigned long duracionEstadoActual = DURACION_VERDE_MS;

// Timers no bloqueantes
unsigned long ultimoEnvioEspNow = 0;
unsigned long ultimaLecturaBrujula = 0;

void setup() {
    Serial.begin(BAUD_RATE);
    delay(500);
    Serial.println("[SEMAFORO] Inicializando...");

    // Inicializar pines de LEDs
    pinMode(PIN_LED_ROJO, OUTPUT);
    pinMode(PIN_LED_VERDE, OUTPUT);
    
    // Estado inicial: Verde para autos (LED verde ON, LED rojo OFF)
    digitalWrite(PIN_LED_ROJO, LOW);
    digitalWrite(PIN_LED_VERDE, HIGH);

    // Inicializar I2C y Brújula
    Wire.begin(PIN_I2C_SDA, PIN_I2C_SCL);
    if (!ControladorBrujulaSemaforo::inicializar()) {
        Serial.println("[SEMAFORO] [ERROR] No se pudo inicializar la brújula QMC5883L!");
    } else {
        Serial.println("[SEMAFORO] Brújula inicializada correctamente.");
    }

    // Inicializar ESP-NOW
    if (!ComunicadorBrazalete::inicializar()) {
        Serial.println("[SEMAFORO] [ERROR] No se pudo inicializar ESP-NOW!");
    } else {
        Serial.println("[SEMAFORO] ESP-NOW inicializado correctamente.");
    }

    tiempoInicioEstado = millis();
    Serial.println("[SEMAFORO] Inicialización completa. Iniciando ciclo FSM...");
}

void loop() {
    unsigned long ahora = millis();

    // ── 1. Máquina de Estados (FSM) del Semáforo ─────────────────────────────
    if (ahora - tiempoInicioEstado >= duracionEstadoActual) {
        // Cambiar de estado
        if (estadoActualAutos == EstadoSemaforoAutos::VERDE) {
            estadoActualAutos = EstadoSemaforoAutos::ROJO;
            duracionEstadoActual = DURACION_ROJO_MS;
            digitalWrite(PIN_LED_ROJO, HIGH);
            digitalWrite(PIN_LED_VERDE, LOW);
            Serial.println("[SEMAFORO] Estado cambiado a: ROJO (Peatones pueden cruzar)");
        } else {
            estadoActualAutos = EstadoSemaforoAutos::VERDE;
            duracionEstadoActual = DURACION_VERDE_MS;
            digitalWrite(PIN_LED_ROJO, LOW);
            digitalWrite(PIN_LED_VERDE, HIGH);
            Serial.println("[SEMAFORO] Estado cambiado a: VERDE (Autos avanzan, Peatones esperan)");
        }
        tiempoInicioEstado = ahora;
    }

    // ── 2. Lectura de la Brújula (Magnetómetro) ──────────────────────────────
    if (ahora - ultimaLecturaBrujula >= INTERVALO_LECTURA_BRUJULA_MS) {
        ultimaLecturaBrujula = ahora;
        if (ControladorBrujulaSemaforo::leerHeading()) {
            Serial.printf("[SEMAFORO] Heading: %.2f°\n", ControladorBrujulaSemaforo::headingActual);
        } else {
            Serial.println("[SEMAFORO] [ERROR] Falló la lectura de la brújula");
        }
    }

    // ── 3. Envío de Telemetría por ESP-NOW ────────────────────────────────────
    if (ahora - ultimoEnvioEspNow >= INTERVALO_ENVIO_MS) {
        ultimoEnvioEspNow = ahora;

        // Calcular el tiempo restante en segundos
        unsigned long transcurrido = ahora - tiempoInicioEstado;
        uint8_t tiempoRestante = 0;
        if (transcurrido < duracionEstadoActual) {
            tiempoRestante = (uint8_t)((duracionEstadoActual - transcurrido) / 1000UL);
        }

        // Construir el payload de estado
        estado_semaforo payload;
        payload.id = 1; // ID del semáforo en la red local
        payload.grados = (uint16_t)ControladorBrujulaSemaforo::headingActual;
        payload.permitidoCruce = (estadoActualAutos == EstadoSemaforoAutos::ROJO) ? 1 : 0;
        payload.tiempo = tiempoRestante;

        // Enviar vía ESP-NOW (broadcast)
        if (ComunicadorBrazalete::enviarEstado(payload)) {
            // Imprimir detalles de debug cada 2 segundos aproximadamente
            static unsigned long ultimaImpresionDebug = 0;
            if (ahora - ultimaImpresionDebug >= 2000UL) {
                ultimaImpresionDebug = ahora;
                Serial.printf("[SEMAFORO] ESP-NOW TX -> Grados: %d, Permitido: %d, Tiempo: %ds\n", 
                              payload.grados, payload.permitidoCruce, payload.tiempo);
            }
        } else {
            Serial.println("[SEMAFORO] [ERROR] Falló el envío ESP-NOW");
        }
    }
}

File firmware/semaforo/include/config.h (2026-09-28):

 #ifndef CONFIG_SEMAFORO_H
#define CONFIG_SEMAFORO_H

// ── Serial ──────────────────────────────────────────────────────────────────
#define BAUD_RATE 115200

// ── I2C — QMC6308 ───────────────────────────────────────────────────────────
// El ESP32 DevKit V1 usa los pines I2C por defecto del framework Arduino:
// SDA = GPIO 21, SCL = GPIO 22
// Dirección I2C del QMC6308: 0x2C
#define PIN_I2C_SDA 21
#define PIN_I2C_SCL 22

// ── LEDs de simulación del semáforo ─────────────────────────────────────────
// LED_ROJO encendido  → semáforo en rojo para autos  → peatón puede cruzar
// LED_VERDE encendido → semáforo en verde para autos → peatón debe esperar
#define PIN_LED_ROJO  25
#define PIN_LED_VERDE 26

// ── Tiempos del ciclo del semáforo (milisegundos) ───────────────────────────
#define DURACION_VERDE_MS 30000UL   // 30 s verde para autos (peatón espera)
#define DURACION_ROJO_MS  30000UL   // 30 s rojo para autos  (peatón puede cruzar)

// ── Comunicación ESP-NOW ─────────────────────────────────────────────────────
// Intervalo de envío del paquete de estado al brazalete.
// Sincronizado con el ciclo de muestreo del brazalete (2Hz = 500ms).
#define INTERVALO_ENVIO_MS 500UL    // Cada 500 ms (2 Hz)

// ── Calibración Hard-Iron (Leaky Integrator) ─────────────────────────────────
// Offset_nuevo = (Offset_anterior * LEAKY_ALPHA) + (Lectura_actual * LEAKY_BETA)
#define LEAKY_ALPHA  0.99f
#define LEAKY_BETA   0.01f

// ── Brújula ──────────────────────────────────────────────────────────────────
// Intervalo de lectura del magnetómetro
#define INTERVALO_LECTURA_BRUJULA_MS 500UL

#endif // CONFIG_SEMAFORO_H

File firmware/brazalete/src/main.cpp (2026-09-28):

#include <Arduino.h>
#include <Wire.h>
#include "../lib/brujula/brujula.h"
#include "../lib/motores/motor.h"
#include "../lib/comunicacion/semaforo/semaforo.h"
#include "../lib/comunicacion/movil/movil.h"
#include "../lib/control/fsm.h"
#include "../include/config.h"

namespace {
    const unsigned long INTERVALO_HEARTBEAT_MS = 2000;
}

unsigned long ultimo_tiempo_heartbeat = 0;

void setup() {
    Serial.begin(BAUD_RATE);
    delay(500);
    Serial.println("\n[BOOT] Iniciando Brazalete ACPI v2.0...");

    // 1. Inicializar Motores
    Serial.println("[BOOT] Inicializando motores...");
    if (!ControladorMotores::inicializar()) {
        Serial.println("[BOOT] [ERROR] Fallo al inicializar motores!");
    } else {
        Serial.println("[BOOT] Motores listos.");
    }

    // 2. Inicializar I2C y Sensores (MPU6050 + QMC5883L) — SDA=GPIO8, SCL=GPIO9
    Serial.println("[BOOT] Inicializando I2C...");
    Wire.begin(8, 9);
    
    Serial.println("[BOOT] Inicializando brujula...");
    if (!ControladorBrujula::inicializar()) {
        Serial.println("[BOOT] [ERROR] Fallo al inicializar la brújula!");
    } else {
        Serial.println("[BOOT] Brújula lista.");
    }

    // 3. Inicializar Comunicaciones (ESP-NOW + BLE)
    Serial.println("[BOOT] Inicializando receptor ESP-NOW (Semaforo)...");
    if (!ComunicadorSemaforo::inicializar()) {
        Serial.println("[BOOT] [ERROR] Fallo al inicializar receptor ESP-NOW!");
    } else {
        Serial.println("[BOOT] Receptor ESP-NOW listo.");
    }

    Serial.println("[BOOT] Inicializando BLE...");
    if (!ComunicadorMovil::inicializar()) {
        Serial.println("[BOOT] [ERROR] Fallo al inicializar BLE!");
    } else {
        Serial.println("[BOOT] BLE listo.");
    }

    // 4. Inicializar FSM
    Serial.println("[BOOT] Inicializando Maquina de Estados...");
    MaquinaEstados::inicializar();

    Serial.println("[BOOT] Inicializacion completa. Sistema en marcha.");
}

void loop() {
    // Actualizar la Máquina de Estados principal (FSM)
    MaquinaEstados::actualizar();

    // Heartbeat de depuración
    unsigned long ahora = millis();
    if (ahora - ultimo_tiempo_heartbeat >= INTERVALO_HEARTBEAT_MS) {
        ultimo_tiempo_heartbeat = ahora;
        Serial.printf("[SYSTEM] Estado FSM: %d | BLE: %s | Semaforo Angulo: %u\n", 
                      (int)MaquinaEstados::obtenerEstadoActual(),
                      ComunicadorMovil::estaConectado() ? "Conectado" : "Desconectado",
                      ComunicadorSemaforo::ultimoEstado.grados);
    }
}

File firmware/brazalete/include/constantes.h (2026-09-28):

#ifndef CONSTANTES_H
#define CONSTANTES_H

#include <math.h>

// ── Matemáticas circulares ────────────────────────────────────────────────────
#define GRADOS_CIRCUNFERENCIA   360.0f
#ifndef M_PI
#define M_PI 3.14159265358979323846
#endif
#define RAD_A_GRADOS            (180.0f / (float)M_PI)
#define GRADOS_A_RAD            ((float)M_PI / 180.0f)

// ── Motores ───────────────────────────────────────────────────────────────────
#define APAGAR_MOTOR            0
// Intensidad reducida para proteger soldaduras (70 % de duty cycle máximo)
#define INTENSIDAD_MOTOR        180
// Motor izquierdo (GPIO 2) requiere +15 de duty para igualar la respuesta táctil
#define INTENSIDAD_MOTOR_IZQUIERDO 195

// ── Acelerómetro MPU6050 (rango ±2g por defecto) ────────────────────────────
// Datasheet: 16384 LSB/g en rango ±2g.
// NOTA: El requisito original indicaba 16600.0, pero el valor correcto del
// datasheet del MPU6050 es 16384.0 LSB/g. Se usa el valor del datasheet.
#define FACTOR_ESCALA_ACCEL     16384.0f

// ── Calibración Hard-Iron (Leaky Integrator) ─────────────────────────────────
// Offset_nuevo = (Offset_anterior * LEAKY_ALPHA) + (Lectura_actual * LEAKY_BETA)
// Con LEAKY_ALPHA=0.99 y LEAKY_BETA=0.01 la calibración converge en ~100 ciclos
#define LEAKY_ALPHA             0.99f
#define LEAKY_BETA              0.01f

// ── Safety check de heading (brazalete) ────────────────────────────────────────
// Si el heading cambia más de este valor en menos de UMBRAL_TIEMPO_SEGURIDAD_MS,
// la lectura se invalida y no se emite señal de cruce
#define UMBRAL_DELTA_HEADING    40.0f
#define UMBRAL_TIEMPO_SAFETY_MS 500UL

// ── Frecuencia de muestreo (2 Hz) ────────────────────────────────────────────
#define INTERVALO_MUESTREO_MS   500UL

// ── Patrones de vibración ─────────────────────────────────────────────────────
// ROJO (cruce autorizado): 3 pulsos largos y espaciados → silencio → repite.
// Sensación: lenta y deliberada ("cruza ahora, con calma").
// Ciclo total ≈ 3 800 ms.
#define DURACION_PULSO_ROJO_MS      300UL   // pulso largo
#define PAUSA_ROJO_MS               700UL   // espacio entre pulsos
#define SILENCIO_ROJO_MS           1000UL   // pausa antes de repetir

// VERDE (esperar): 3 pulsos rápidos → 3 s de silencio → repite.
// Sensación: ritmo rápido ("todavía no, todavía no").
// Ciclo total ≈ 4 100 ms.
#define DURACION_PULSO_VERDE_MS     100UL   // pulso corto
#define PAUSA_VERDE_MS              500UL   // espacio entre pulsos
#define SILENCIO_VERDE_MS          3000UL   // silencio largo entre grupos

// Direccional (usuario mal orientado): un pulso corto cada ~900 ms.
#define DURACION_PULSO_DIR_MS       200UL
#define PAUSA_DIR_MS                700UL

#endif // CONSTANTES_H

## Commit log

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2026-05-09 refactor: implementar directorio dedicado al firmware
    [partitions.csv]
2026-05-09 refactor: implementar directorios docs y tools para la documentacion y el dashboard
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2026-05-11 chore: eliminar archivos
    [partitions.csv]
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2026-05-18 feat: implementar la estructura para la comunicacion de la pulsera mediante ESP-NOW
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2026-05-19 feat: implementar la cabecera con la descripcion del controlador para el acelerometro
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2026-05-21 feat: implementar funcion para controlar los momentos de vibracion de los motores
2026-05-21 feat: implementar logica de la funcion para controlar los momentos de vibracion de los motores
2026-05-21 feat: implementar la cabecera de la funcion para determinar la direccion del semaforo
2026-05-21 feat: implementar la logica de la funcion para determinar la direccion del semaforo
2026-05-21 feat: implementar la funcion para verificar la direccion en el metodo de verificacion del semaforo en la brujula
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2026-05-21 fix: inicializar los atributos de los sensores en los archivos .cpp
2026-05-21 feat: implementar la cabecera de la vibracion para indicar un error en la inicializacion de la pulsera
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2026-05-23 feat: implementar la logica para indicar un error con patrones de vibracion
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2026-06-06 feat: implementar la estructura para la comunicacion de datos desde el semaforo
2026-06-17 feat: implementar la logica final para el correcto funcionamiento del componente de firmware y documentar
    [config.h, constantes.h, main.cpp]
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2026-07-13 feat: implement electronic circuit for 'acpi_pulsera'
    [pcb_design.kicad_pcb, pcb_design.kicad_sch]
2026-07-14 feat: completar esquema electronico de la pulsera con magnetometro real y carga LiPo
    - Reemplaza el conector generico del QMC6308 por su simbolo/footprint real
    (WLCSP-4, libreria propia en pcb_design/libs) para ensamblaje SMT en JLCPCB
    - Agrega regulador de 1.8V (AP2112K-1.8) y level shifter I2C (TXS0102DCU),
    porque el QMC6308 no soporta el bus de 3.3V ya existente
    - Agrega circuito de carga LiPo (MCP73831) alimentado desde el mismo USB-C,
    con conector JST-PH para la bateria
    - Reemplaza los transistores de simulacion por MMBT3904 reales y asigna
    footprint a todos los componentes (incluido el USB-C: HRO TYPE-C-31-M-12)
    - Corrige la alimentacion del ESP32, los pull-ups I2C faltantes y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
    [pcb_design.kicad_sch]
2026-07-14 feat: implement interruptor to turn on or off the 'acpi_pulsera'
    [pcb_design.kicad_sch]
2026-07-14 feat: implement correct footprint of JST connectors
    [pcb_design.kicad_sch]
2026-07-14 feat: implement pcb initial architecture
    [pcb_design.kicad_pcb]
2026-08-03 feat: implement complete pcb design
    [pcb_design.kicad_pcb, pcb_design.kicad_sch]
2026-08-03 feat: implement pcb fabrication settings
    [pcb_design-B_Cu.gbl, pcb_design-B_Mask.gbs, pcb_design-B_Paste.gbp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]
2026-09-16 chore(electronics): cambio en la estructura del directorio para la pcb
    pasa ade llamarse 'pcb_desing' a 'electronics' y pasara a contener ahora los esquematicos de los disenos electronicos para la placa de ACPI
    [pcb_design-B_Cu.gbl, pcb_design-B_Mask.gbs, pcb_design-B_Paste.gbp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]
2026-09-16 chore(all): renombrar el directorio de la aplicacion movil, eliminar el directorio 'tools' que estaba obsoleto, eliminar Justfile que ya no es usado en la version actual
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2026-09-21 feat(electronics): implement component references on KiCad symbols library as project configurations
    [acpiv3-new-design.kicad_pcb, acpiv3-new-design.kicad_sch, esp32c3-super-mini.kicad_sch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]
2026-09-21 fix(electronics): corregir drivers de motor y limpiar seguimiento de git
    Los dos canales de vibracion estaban mal cableados: el motor colgaba entre
    colector y emisor sin llegar nunca a la bateria, el emisor no iba a tierra y
    el diodo de flyback quedaba en serie en el retorno y en directa.
    Topologia corregida en ambos canales:
    - motor entre +BATT y el colector del PN2222A
    - diodo en paralelo con el motor, catodo a +BATT (bloquea en operacion normal)
    - emisor a GND, unificado con el negativo de la bateria y la tierra de U1/U2
    - base via resistencia a GPIO4 (canal 1) y GPIO10 (canal 2)
    El canal 2 pasa de GPIO20 a GPIO10: GPIO20 es U0RXD y habria peleado con la
    consola serie del ESP32-C3.
    Lim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
    [acpiv3-new-design.kicad_sch]
2026-09-21 chore(electronics): dejar de rastrear .history del proyecto pcb-non-viable
    Mismo caso que en acpiv3-new-design: el historial local de KiCad estaba
    registrado como gitlink sin .gitmodules. La regla .history/ de .gitignore ya
    lo cubre una vez deja de estar rastreado. Los archivos siguen en disco.
2026-09-27 chore(electronics): discard KiCad schematic and pcb files
    KiCad was discarded as a pcb design application, now I will use EasyEDA because ismore easy get and use the comercial sensors and components in this APCI version
    [acpiv3-new-design.kicad_pcb, acpiv3-new-design.kicad_sch, esp32c3-super-mini.kicad_sch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]
2026-09-27 feat(electronics): implement new ACPI v3 bracelet schemetic files
    here in this commit I add the .pdf schematic file, .json of EasyEDA schematic and the netlist
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2026-09-27 feat(electronics): update ESP32C3 Super Mini footprint
    use THT footprint in schematic design
2026-09-28 feat(firmware): adaptar driver del magnetometro al QMC5883L del GY-271
    El modulo fisico es un GY-271 con QMC5883L (0x0D, chip ID 0xFF),
    confirmado con escaneo I2C. El driver estaba escrito para el QMC6308.
    - direccion 0x0D; init: soft reset (0x80 -> 0x0A), periodo SET/RESET
    (0x01 -> 0x0B) y modo continuo 200 Hz, +-8 G, OSR 512 (0x1D -> 0x09)
    - +-8 G para no saturar con el iman de los motores de vibracion
    - aviso por Serial si el chip ID no es 0xFF
    - datos desde el reg 0x00; los 6 bytes se leen en orden a un arreglo,
    porque el orden de evaluacion de Wire.read() | Wire.read() << 8
    no esta definido en C++
    - documentacion y comentarios actualizados de QMC6308 a QMC5883L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
    [main.cpp]
2026-09-28 refactor(all): renombrar pulsera a brazalete en firmware, app y docs
    - carpeta firmware/pulsera -> firmware/brazalete
    - nombre BLE ACPI_Pulsera -> ACPI_Brazalete en firmware (NimBLE) y app
    (BLEManager, deviceId del SessionLogger). Firmware y app deben
    actualizarse juntos para que el celular encuentre el dispositivo
    - identificadores: EstadoPulsera, ComunicadorPulsera (y sus archivos
    comunicador_pulsera.*), PulseraData.kt, pulseraData y callbacks, y
    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
2026-09-28 feat(electronics): implement new JST footprint and schematic in acpi bracelet shematic, change transistor footprint
2026-09-29 feat(electronics): design ACPI bracelet PCB
    [BOM_acpi-pcb-design.csv]
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2026-10-01 feat(electronics): ACPI pcb update and new schematic and pcb model
    [BOM_acpi-pcb-design.csv]
2026-10-04 fix(electronics): correct shape of copper traces
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2026-10-26 feat(3d): add ACPI bracelet case with centered lid pins
    Case, cover and assembly preview of the bracelet enclosure. The cover
    pins and the case holes are round (1.4 mm pins in 1.8 mm holes, 0.2 mm
    radial clearance), centered on each wall corner and symmetric, so the
    lid fits in either orientation. The USB opening sits at 5-10 mm.
2026-10-27 refactor(brazalete): build with Arduino IDE or ESP-IDF instead of PlatformIO
    Move lib/ and include/ into src/ so the folder is a plain Arduino sketch
    (brazalete.ino) that ESP-IDF can also build with arduino-esp32 as a
    component (main/main.cpp includes the sketch).
    - Pins and I2C addresses for PCB v3.5 now live in src/config.h
    (SDA 8, SCL 9, motors on GPIO10/GPIO3, MPU6500 at 0x68, QMC5883L at 0x0D).
    - LEDC and ESP-NOW callbacks compile on both core 2.x and 3.x.
    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
2026-10-27 fix(brazalete): lower motor intensity to protect the solder joints
    On PCB v3.5 the motors run straight from VBAT (3.7-4.2 V); at 180/255
    the right motor shook hard enough to threaten its solder joints.
    Start at 120/255 (left keeps its +15 offset) and tune with test 03.
2026-10-27 test(brazalete): add hardware sketches for I2C, sensor ID and motors
    - 01_escaneo_i2c: lists responding addresses and checks SDA/SCL pull-ups.
    - 02_identificar_sensores: reads each chip ID register (MPU6050/6500/9250,
    QMC5883L/HMC5883L/QMC5883P, AK8963) and prints the config.h lines.
    - 03_prueba_sensores_motores: prints accel, gyro, temperature and compass
    at 2 Hz and drives each motor from serial commands (pulses, sweep,
    hold at the current intensity).
2026-10-27 feat(semaforo): sign ESP-NOW packets and switch lights every 25 s
    Packets now start with the 4-byte signature "ACPI" (9 bytes total).
    The bracelet only accepts packets with the exact size and that
    signature, so stray ESP-NOW broadcasts on the channel can no longer
    look like the traffic light. The struct uses #pragma pack(1), which
    GCC and MSVC both understand.
    Each light now lasts 25 s, shorter than the 30 s without packets that
    will send the bracelet to standby.
2026-10-27 feat(brazalete): one-shot vibration patterns driven by a packet evaluator
    Replace the looping vibration routines with the four patterns approved in
    patrones.md (traffic light detected, turn left/right, crossing allowed,
    crossing forbidden).
    - ControladorPatrones (src/vibracion) plays a pattern once and enforces at
    least 3 s between pattern starts, never overlapping, to protect the weak
    solder joints. It has no Arduino dependency.
    - EvaluadorSemaforo (src/control) diffs each packet against the previous
    one (new traffic light, light change, other id ignored), tracks the
    user's orientation with 10 deg hysteresis and decides which pattern to
    request. With no event, nothing vibrates.
    -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
2026-10-27 fix(semaforo): read QMC6308 bytes in a defined order
    "Wire.read() | (Wire.read() << 8)" leaves the evaluation order of the two
    reads unspecified, so LSB and MSB could swap and corrupt the heading the
    traffic light broadcasts. Read the six bytes into an array first, as the
    bracelet drivers already do.
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2026-10-27 fix(brazalete): make the compass safety check actually run
    The check only compared readings taken less than 500 ms apart, but the
    FSM samples every 500 ms, so it practically never fired and a sudden
    wrist turn could still produce a wrong-side turn pulse. Compare against
    the previous sample when it is younger than twice the sampling interval,
    with a static_assert guarding the relation.
    Also share the angle math: arcoMenor() is used by the safety check and
    desviacionEnfrentamiento(), and giroParaEnfrentar() replaces the inline
    "hs + 180" expression in the FSM, so the test exercises the production
    helper instead of a copy.
2026-10-27 fix(brazalete): shut BLE down safely when entering standby
    - Disconnect the phone and wait for the event before BLEDevice::deinit():
    deinit frees the server before stopping NimBLE, so a live connection's
    disconnect event reached a freed BLEServer and onDisconnect restarted
    advertising mid-shutdown.
    - Skip re-advertising while shutting down.
    - Delete the characteristics after deinit; the library never frees them.
    The BLEService itself has a private destructor, so a few hundred bytes
    still leak per SENSING -> STANDBY cycle; the heartbeat prints the free
    heap to keep an eye on it.
2026-10-27 fix(brazalete): harden standby against floating pins and stale packets
    - During light sleep the C3 isolates GPIOs; keep both motor pins as
    inputs with pull-down so the transistor bases never float and a motor
    cannot turn on without an event.
    - Drop a packet that arrives just as a listening window closes, so the
    next window does not wake up on 5 s old data.
    - If a window is closed late, push the next one back instead of opening
    it right away (never two windows back to back), with tests.
    - Put the MPU6500 (sleep bit) and the QMC5883L (standby mode) to sleep
    while in standby and reconfigure them on the way out.
2026-10-27 refactor(brazalete): share the crossing loop between the FSM and the tests
    The scenario tests re-implemented the SENSING_CROSSING loop by hand, so
    they could drift from fsm.cpp. CoordinadorCruce now holds one loop pass
    (packet -> close finished pattern -> 2 Hz orientation when no motor
    vibrates -> orquestar -> motor output) plus the 30 s no-packet timeout.
    The FSM plugs in the real compass and motors; the simulator plugs in
    fake readings.
    Also from the review:
    - Rest SILENCIO_TRAS_PATRON_MS (1 s) after every pattern, so a light
    change during the 4.5 s green no longer plays red back to back.
    - Close a finished pattern before deciding whether to sample, so the
    first decision after a patte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
2026-10-27 feat(3d): parametric case generator with a fit-test frame
    generar_case.py builds the box and lid from parameters (PCB outline,
    wall thickness, lid lip clearance and crush ribs for a friction fit) and
    exports the STLs. ACPI-Prueba-Ajuste.stl is a small frame to print first
    and check the lid fit before printing the full case.
2026-10-27 fix(brazalete): lower motor intensity to 100/255
    120/255 still shook the motors too hard for their solder joints. Both
    motors now run at 100/255 (about 39 % duty). The inherited +15 offset of
    the left motor was never confirmed on this board, so it is dropped until
    both motors can be compared. Test sketch 03 starts at 100 as well.
2026-10-27 feat(protocolo): CRC-8 and range checks on traffic light packets
    2.4 GHz interference (phones, laptops, headphones) mostly drops frames,
    but any packet that does arrive altered, or that another device builds
    with the same "ACPI" prefix, must not reach the evaluator. Packets are
    now 10 bytes: the last one is a CRC-8 (poly 0x07) of the rest, written
    by sellarPaqueteSemaforo() on the traffic light. The bracelet accepts a
    packet only with the exact size, the signature, a matching CRC,
    grados < 360 and permitidoCruce 0 or 1.
    The ESP-NOW callback validates before taking the lock, so a flood of
    foreign packets is rejected quickly and never holds up loop(). Tests
    cover single-bit corruption of ever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
2026-10-27 feat(brazalete): stay stable under 2.4 GHz interference
    - A light change only counts after CONFIRMACIONES_CAMBIO_LUZ (2)
    consecutive packets agree; a stray packet with the opposite light, from
    interference or another device, never makes the bracelet vibrate. The
    real change is announced 0.5 s later.
    - enableLoopWDT() on both firmwares: if loop() stops returning for 5 s
    the ESP32 resets and boots into standby with the motors off. A
    static_assert keeps the standby light sleep below that timeout, and the
    ESP-IDF sdkconfig.defaults pin the same 5 s task watchdog.
    - BLE writes from nearby phones are truncated and rate limited before
    printing, so they cannot flood Serial or the NimBL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
2026-10-27 fix(brazalete): turn the motor pins off first thing at boot
    PCB v3.5 has no base-to-ground resistor on the motor transistors, so the
    bases float from reset until the pins are configured. Setup used to wait
    500 ms for Serial first; now ControladorMotores::inicializar() runs before
    anything else, shortening the window in which a motor could twitch.
2026-10-28 test(brazalete): add an I2C bus diagnostic sketch
    Sketch 04 bit-bangs the bus to tell apart the causes of a broken scan
    (every address or none answering): it frees a stuck slave with nine
    clocks and a STOP, probes known and unknown addresses, reports bits
    another device pulled low, and scans with Wire at 100 and 10 kHz. It
    helped find a cracked 3V3 trace that left the sensors unpowered.
2026-10-28 feat(brazalete): print the last reset reason at boot
    Brownout, watchdog and panic resets look the same from outside (the
    bracelet just restarts). Printing esp_reset_reason() at boot makes a
    reset loop visible on the serial monitor, e.g. a power trace that only
    makes contact now and then.
2026-10-28 fix(brazalete): swap the motor pins to match the worn bracelet
    Tested on the board with sketch 03: with the bracelet on, the motor on
    GPIO3 (Q2, CN3) sits on the right and the one on GPIO10 (Q1, CN2) on the
    left, the opposite of what the firmware assumed, so every turn pulse
    would have pointed the wrong way. Swap PIN_MOTOR_DERECHO /
    PIN_MOTOR_IZQUIERDO in config.h and in test sketch 03, and update the
    docs.
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2026-10-29 fix(firmware): accurate compass and turn guidance for a 5° crossing cone
    The heading drifted and the bracelet sent the user to the wrong side after the
    light cue. Simulated with the real drivers and a fake I2C bus to find why.
    Compass (bracelet and traffic light):
    - Replace the "leaky integrator", which subtracted the reading's own average:
    it erased the Earth's field (random heading after ~4 min on the traffic
    light, +42° error after a turn on the bracelet). Hard-iron is now a
    least-squares sphere fit done once (at boot if missing, or 'c' on serial)
    and kept in NVS.
    - Fix tilt compensation (it took atan2 in the sensor frame: 16° off at a
    30°/30° wrist tilt), average 4 sample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
2026-10-31 fix(app-movil): make the BLE client find and reconnect to the bracelet reliably
    The bracelet only turns BLE on next to a traffic light, so the app has to
    catch it in short windows. The old client often missed them or got stuck:
    it waited up to 30 s between 10 s scans, dropped the bracelet when iOS
    reported a cached GAP name ("ACPI_Pulsera"), had no connect timeout, could
    not cancel a connection in progress and never noticed a connection left
    open by a JS reload.
    cliente-ble.ts is rewritten around injected dependencies, and the
    decisions now live in pure functions in ble/decisiones.ts:
    - Accept any peripheral that passed the service UUID filter and prefer
    advertising.localName; log every d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
2026-10-31 docs: update the main README and keep the Infomatrix report out of git
    README:
    - Describe the system as it works today: the QMC6308 traffic light at
    2 Hz with a signed 10-byte packet, the bracelet with QMC5883L + MPU6500,
    a 5 Hz compass and standby, the React Native app for iOS and Android,
    and the API + website in Snt8/acpi-website.
    - List electronics/, 3D-models/ and assets/, and drop the Justfile, which
    no longer exists.
    - Say that the bracelet only turns BLE on next to a traffic light.
    - Credit the authors: Edy S. Avila, plus the original ACPI v2 team, Dilan
    Osorio, Andrea Cárdenas and Nicolás Rodríguez (Dilaansg/ACPI).
    .gitignore: ignore the Infomatrix template, drafts, re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
2026-11-12 fix(semaforo): show the pedestrian light on the LEDs
    The traffic light is a pedestrian signal, but its LEDs showed the car
    light: green LED while pedestrians had to wait. Now the green LED means
    the pedestrian may cross (permitidoCruce = 1) and the red LED means wait.
    The cycle starts on red, the safe state.
2026-11-12 fix(brazalete): never report a stale light and come back from standby
    Light freshness
    - After 3 s without a packet that confirms the light (LUZ_VIGENTE_MS),
    the bracelet stops reporting it: BLE telemetry sends "st":4 and
    "lz":null, and the light vibration waits for fresh packets. Before, the
    last light was repeated for up to 30 s.
    - A first packet with a different light after a gap no longer makes the
    old light current again.
    Standby
    - Going from a crossing back to standby is now a clean ESP32 restart
    instead of shutting BLE and WiFi down while running; the restart skips
    calibration. Three failed ESP-NOW starts in a row also restart.
    - Light sleep is off for now (STANDBY_LIGHT_S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
2026-11-12 fix(brazalete): go back to the firmware that worked, with only the needed fixes
    The previous bracelet changes (stale-light handling, restart-based
    standby, new telemetry state, light sleep off) are reverted: the firmware
    is again the one from 7685215, except for:
    - Calibration: the accelerometer axes are only adopted when the detection
    is clear (enough tilted poses and a clear margin); otherwise the stored
    ones are kept. Calibration and axes are saved together and read back to
    verify. 'c' keeps the stored axes as a fallback.
    - App commands: RECALIBRATE (same as 'c', without a cable) and RESTART.
    At the end of a boot calibration the bracelet vibrates once (long) when
    it is saved an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
2026-11-12 feat(brazalete): align the bracelet with the traffic light from the app
    Face to face, the bracelet and the traffic light measured 140 deg instead
    of 180 deg: their magnetometer X axes do not point exactly at their
    fronts, so the bracelet kept asking to turn right. The new ALIGN command
    (button "Alinear con el semaforo" in Diagnostico) takes the turn the
    bracelet thinks is missing while the person faces the light, adds it to
    the heading correction and stores it in NVS. Recalibrating keeps it.
    It needs a packet from the light and a valid (still) reading; on success
    the test pattern sounds and the "giro" shown in Diagnostico drops to
    about 0.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
